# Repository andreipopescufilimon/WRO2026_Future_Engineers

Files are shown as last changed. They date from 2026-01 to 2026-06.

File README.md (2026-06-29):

# WRO2026 Future Engineers – HyperLine Robotics Team
---

Repository of HyperLine Robotics Team competing in the **World Robot Olympiad (WRO) 2026**, Future Engineers category. 

### 🔗 Links

<p align="left">
  <a href="https://hyperlinerobotics.com/" target="_blank">
    
  </a>

  <a href="https://www.youtube.com/@HyperLineRobotics_Team" target="_blank">
    
  </a>

  <a href="https://www.instagram.com/hyperlinerobotics_team/" target="_blank">
    
  </a>

  <a href="https://x.com/HLR_Team" target="_blank">
    
  </a>

  <a href="https://www.facebook.com/hyperlineroboticsteam" target="_blank">
    
  </a>

  <a href="https://github.com/andreipopescufilimon" target="_blank">
    
  </a>

  <a href="https://oshwlab.com/bicicleta11/works" target="_blank">
    
  </a>
</p>

## ❤️ Sponsors and Partners

<table align="center" cellspacing="12">
<tr>
  <td bgcolor="#ffffff" align="center" width="200">
    
  </td>
  <td bgcolor="#ffffff" align="center" width="200">
    
  </td>
  <td bgcolor="#ffffff" align="center" width="200">
    
  </td>
  <td bgcolor="#ffffff" align="center" width="200">
    
  </td>
</tr>

<tr>
  <td bgcolor="#ffffff" align="center">
    
  </td>
  <td bgcolor="#ffffff" align="center">
    
  </td>
  <td bgcolor="#ffffff" align="center">
    
  </td>
  <td bgcolor="#ffffff" align="center">
    
  </td>
</tr>
</table>

---

## 📚 Table of Contents

- [👥 The Team](#the-team)
- [🎯 Challenge Overview](#challenge-overview)
- [🤖 Our Robot](#our-robot)
- [📊 Performance Metrics](#performance-metrics)
- [⚖️ Engineering Trade-Offs](#engineering-tradeoffs)
- [🔬 Testing & Iterations](#testing-iterations)
    - [📊 Quantitative testing](#quantitative-testing)
- [⚙️ Mobility Management](#mobility-management)
  - [🚗 Drivebase](#drivebase)
    - [🔧 Drivetrain](#drivetrain)
    - [⚙️ Torque and Speed Reasoning](#torque)
    - [⚙️ Motor](#motor)
    - [🛞 Wheels](#wheels)
    - [🔌 Motor Driver IFX9201SG](#motor-driver)
    - [🌪️ Impeller](#impeller)
  - [🔄 Steering](#steering)
    - [🔄 Steering Servo Motor](#servo-motor)
  - [📡 Sensor Placement](#sensor-placement)
  - [🏎️ Chassis & Component Mounting](#chassis)
    - [✨ Key Features & Advantages](#key-features)
    - [🔧 Assembly Process](#assembly-process)
      - [🔧 Assembly Process Video](#assembly-process-video)
      - [🔧 3D print the parts](#3d-print-the-parts)
      - [🔧 Assemble the robot](#assembly)
- [🛠️ Power and Sense Management](#power-and-sense-management)
  - [🔋 Li-Po Battery](#li-po-battery)
  - [🖥️ Arduino Nano ESP32](#arduino-nano-esp32)
  - [🧭 IMU Sensor BMI088](#imu-sensor-bmi088)
  - [📷 OpenMV RT1062 Camera](#openmv-rt1062-camera)
  - [⚙️ Drive Motor](#drive-motor)
  - [⚙️ Motor Driver IFX9201SG](#motor-driver)
  - [🔄 Steering Servo MG90S](#steering-servo)
  - [⚙️ Impeller](#impeller)
  - [📏 Pololu PWM Distance Sensor](#distance-sensors)
  - [🔌 Voltage Regulator D24V50F5](#voltage-regulator)
  - [🛠️ PCB Design](#pcb-design)
  - [⚡ Power Consumption](#power-consumption)
  - [🔋 Power and Sensor Validation](#power-and-sensor-validation)
  - [⚠️ Power failure points and mitigation](#power-failure-points)
- [💻 Components coding](#components-coding)
  - [🧠 Software Architecture](#software-architecture)
  - [🔄 Robot State Machine](#state-machine)
  - [⚡ Drive motor](#drive-motor-coding)
  - [🌪️ Impeller](#impeller-coding)
  - [🎮 Servo motor](#servo-motor-coding)
  - [🧭 IMU](#imu-coding)
  - [📡 Distance sensors](#distance-sensors-coding)
  - [📷 Camera](#camera-coding)
- [📝 Obstacle Management](#obstacle-management)
  - [🏁 Open Round](#open-round) 
  - [⚡ Final Round](#final-round)
  - [🅿️ Start from Parking](#start-from-parking)
  - [🅿️ Parking](#parking)
- [⚠️ Edge Cases and Failure Handling](#edge-cases)
- [📽️ Performance Video](#performance-video)
- [💰 Cost Analysis](#cost-analysis)
  - [📦 Component Costs](#components-costs)
  - [🔌 PCB Manufacturing Cost](#pcb-cost)
  - [🖨️ 3D Printing Cost](#3d-printing-cost)
  - [🔩 Other Materials (Screws, Nuts, Miscellaneous)](#other-materials-cost)
  - [💵 Total Cost](#total-cost)
- [🔁 Reproducibility Guide](#reproductibility-guide)
- [🎲 Randomizer](#randomizer)
- [📂 Resources](#resources)
- [📜 License](#license)

## 📂 Folder Structure

This repository is organized as follows:

```
📦 WRO2026_Future_Engineers
├── 📁 3D-models             # Contains 3D design files for the robot's components
│   ├── 📁 old-3D-models     # Previous versions of 3D models
├── 📁 electrical-schematics # Circuit diagrams and wiring
├── 📁 github-commits        # Commit logs and change tracking details for this repository
├── 📁 media                 # Images and videos 
│   ├── 📁 robot-photos      # Photos of the robot
│   ├── 📁 team-photos       # Pictures of team members and teamwork
│   └── 📁 video             # Recorded testing
├── 📁 other                 # Contains files that do not fit into other categories
├── 📁 src                   # Main source code for the robot
├── 📁 technical-draws       # Technical drawings and mechanical blueprints
├── 📁 video                 # Videos of our robot
├── 📄 LICENSE               # MIT License for the project
└── 📄 README.md             # Main documentation for the project
```

---

## 👥 The Team 

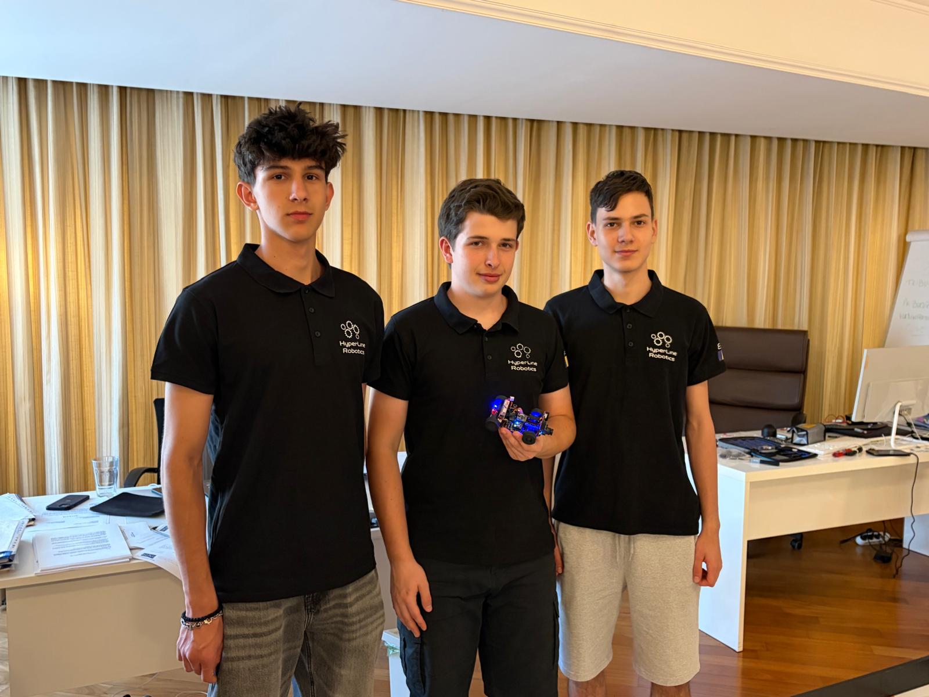
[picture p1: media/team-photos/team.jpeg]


### **Popescu Filimon Andrei Cosmin** (middle)
**Age:** 18 <br>
**High School:** International Computer High School Bucharest (ICHB)  
**View my portofolio**: [https://andreipopescufilimon.com/](https://andreipopescufilimon.com/)

**Description:**  
Hi! I’m Andrei from Romania, and this is my sixth WRO season. This is my second season in Future Engineers, as before I competed in the Robomission category. I am passionate about robotics, especially electronics and the latest algorithms and tech. Over the years, I have worked on multiple robotics projects, including line followers, sumo bots, and air quality modules. I am the founder of HyperLine Robotics Team, where I build and develop advanced robotics projects with my team. Apart from robotics, I also enjoy cybersecurity, programming, and cycling.

---

### **Horia Simion** (left)
**Age:** 17 <br>
**High School:** National College "Mihai Viteazul" (CNMV)

**Description:**  
Hi! I’m Horia from Romania, and this is my third WRO season competing alongside Andrei. I have participated in RoboMission multiple times, gaining valuable experience in solving various problems that may arise while building a robot. I have a strong interest in technology and robotics and am always eager to learn and experiment with new ideas!

---

### **Eduard Alexandru Vasile** (right)
**Age:** 16 <br>
**High School:** Liceul Teoretic Alexandru Ioan Cuza

**Description:**  
Hi! I’m Eduard from Romania. I’m passionate about robotics, especially building and testing competitive robots. I have worked on sumo robots, and recently I started developing line follower robots as well. I also enjoy driving and flight simulators, where I like exploring realistic control, precision, and performance.

Apart from robotics, I love MTB, video games, and cybersecurity. I’m always interested in learning new technologies, improving my skills, and working on projects that challenge me both technically and creatively.

---

## 🎯 Challenge Overview 

The **WRO 2026 Future Engineers** challenge pushes teams to develop a **fully autonomous vehicle** capable of navigating a **dynamic and randomized racetrack** using **sensors, computer vision, and advanced control algorithms**. The goal is to complete **multiple laps** while adapting to randomized obstacles, following **strict driving rules**, and successfully executing a **parallel parking maneuver** at the end of the course.

### 📌 Competition Format 

- **🏁 Open Challenge**: The vehicle must complete **three (3) laps** on a track with **randomly placed inside walls**.

- **🚦 Obstacle Challenge**: The vehicle must complete **three (3) laps** while detecting and responding to **randomly placed red and green traffic signs**:
  - 🟥 **Red markers** ➜ The vehicle must stay on the **right side of the lane**.
  - 🟩 **Green markers** ➜ The vehicle must stay on the **left side of the lane**.
  
  After completing the three laps, the vehicle must **locate the designated parking zone** and perform a **precise parallel parking maneuver** within a limited space, adding an extra layer of difficulty.
  
- **📑 Documentation**: Each team must maintain a **public GitHub repository** showcasing their **engineering process, vehicle design, and source code**.

### 🏆 Scoring & Evaluation
Scoring is based on **accuracy, technical documentation and speed**, rewarding teams that balance **efficiency, adaptability, and innovation**. This challenge not only tests **robotics and programming skills** but also promotes **problem-solving, teamwork, and engineering creativity**.

🔗 **Find out more about the challenge [here](https://wro-association.org/wp-content/uploads/WRO-2026-Future-Engineers-Self-Driving-Cars-General-Rules.pdf).** 🚀

---

## 🤖 Our Robot 
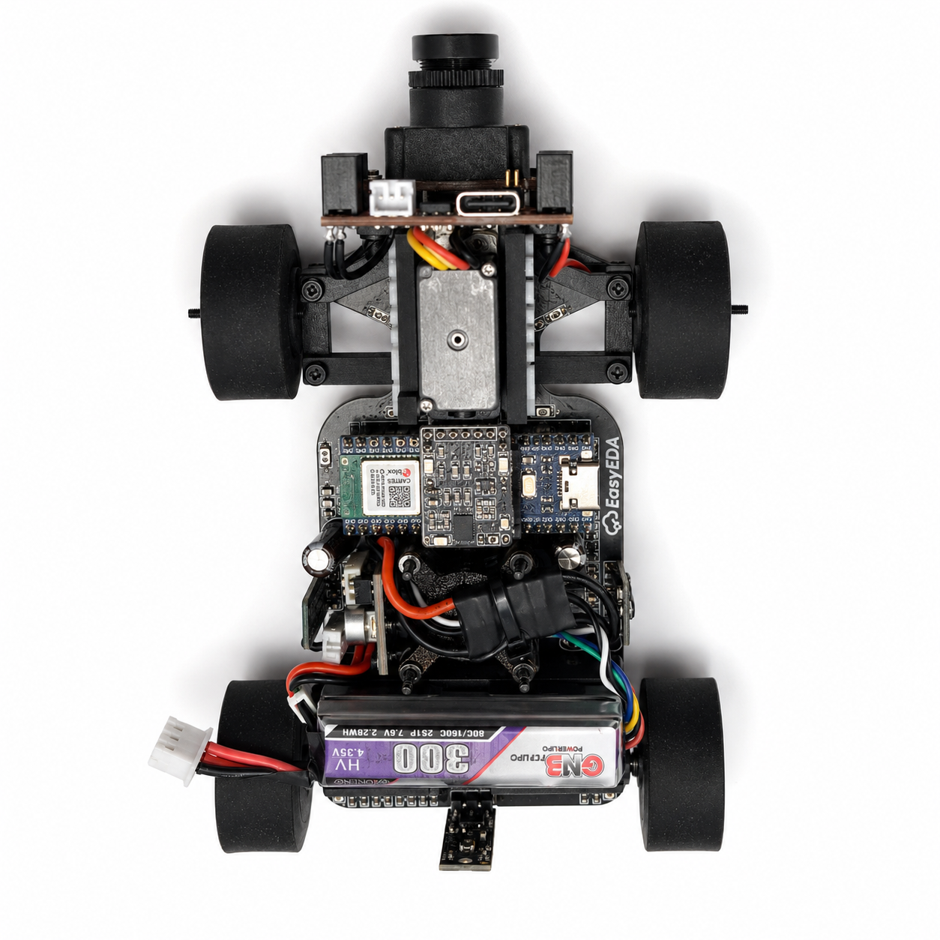
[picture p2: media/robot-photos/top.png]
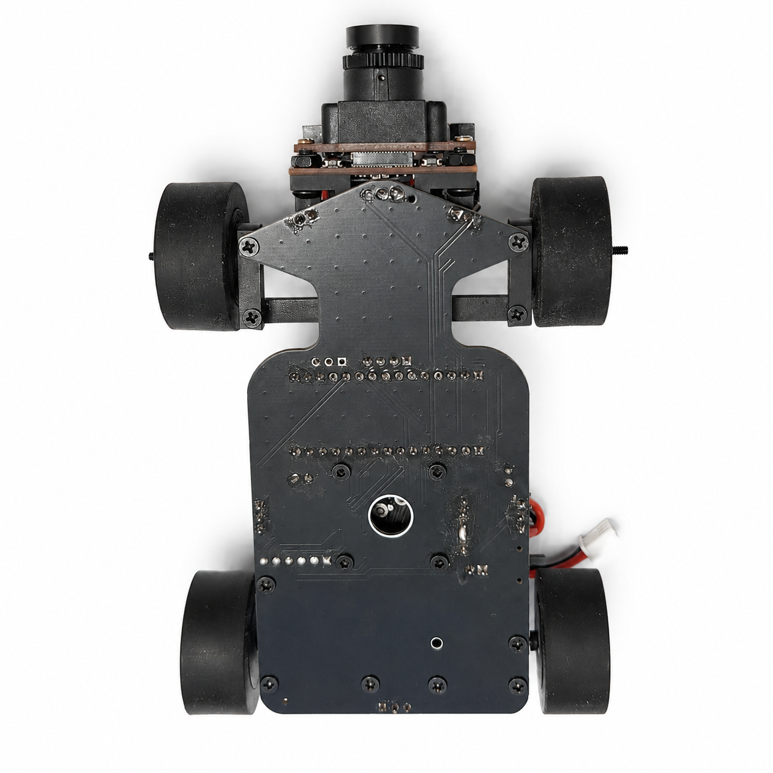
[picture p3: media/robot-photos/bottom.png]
|  |  |
|---|---|
| <p align="center"><b>Top</b></p> | <p align="center"><b>Bottom</b></p> |

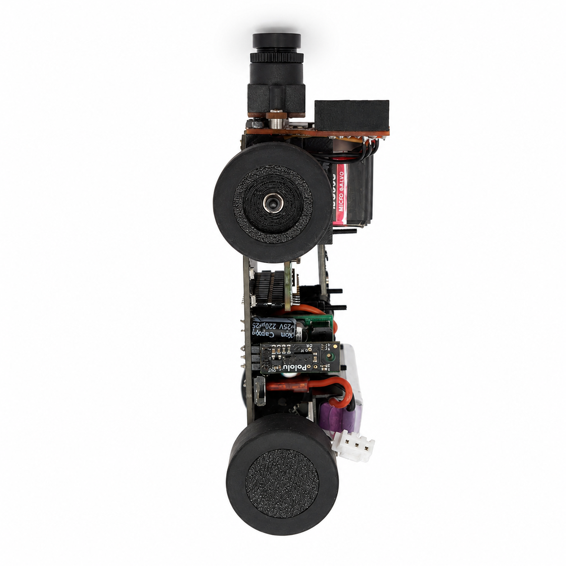
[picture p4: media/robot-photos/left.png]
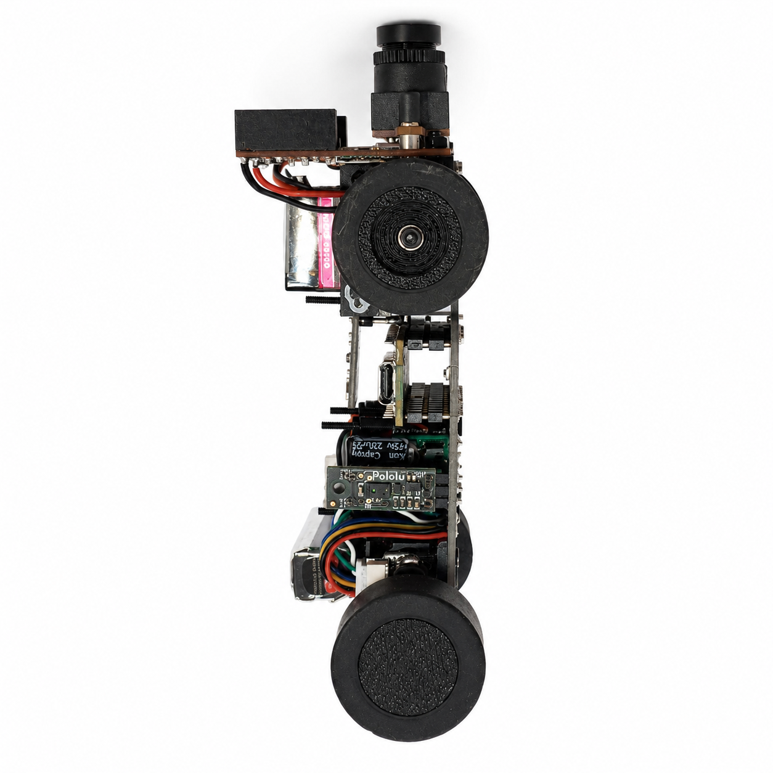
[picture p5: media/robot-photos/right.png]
|  |  |
|---|---|
| <p align="center"><b>Left</b></p> | <p align="center"><b>Right</b></p> |

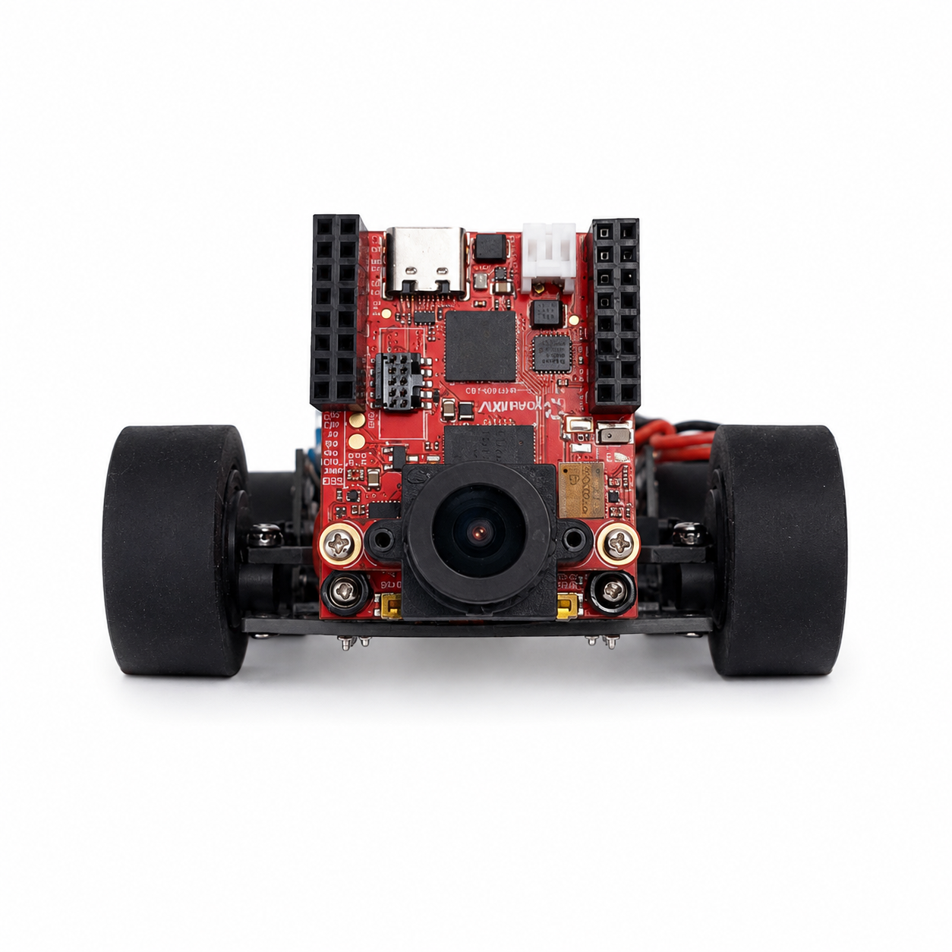
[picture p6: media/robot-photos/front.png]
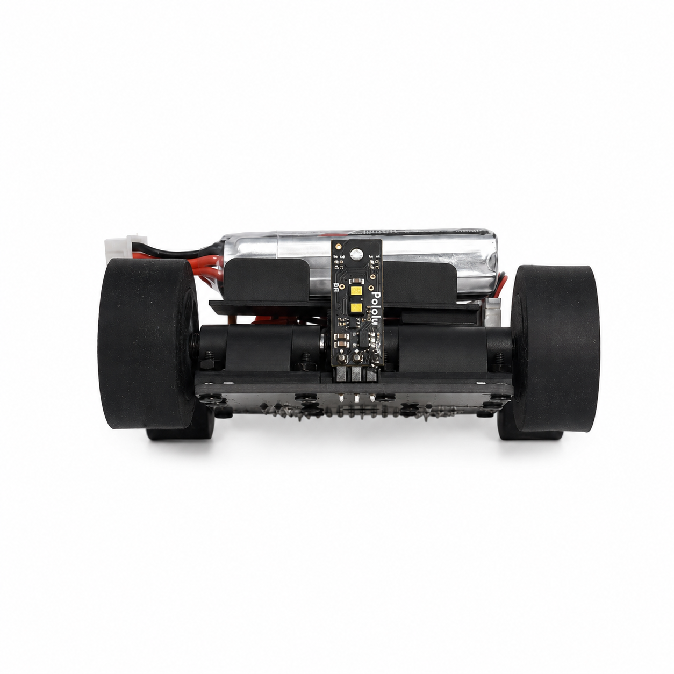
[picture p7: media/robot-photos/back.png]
|  |  |
|---|---|
| <p align="center"><b>Front</b></p> | <p align="center"><b>Back</b></p> |

Robot Specifications:
| Parameter | Value |
|---|---|
| Robot Length | ~145 mm |
| Robot Width | ~65 mm |
| Robot Height | ~55 mm |
| Total Weight | ~200 g |
| Wheelbase | ~65 mm |
| Ground Clearance | ~6 mm |
| Main Controller | Arduino Nano ESP32 |
| Vision System | OpenMV RT1062 |
| Drive System | Rear differential drive |
| Steering System | Parallel steering |
| Drive Motor | Pololu 30:1 HPCB Gearmotor |
| Steering Servo | MG90S |
| Downforce System | 10000KV BLDC Impeller |
| Battery | 2S Li-Po 300mAh |
| Maximum Stable Speed | ~3 m/s |
| Camera Processing Speed | ~40 FPS |
| Maximum Steering Angle | ~85° |
| Peak Current Consumption | ~7 A |
| Communication Protocols | UART, I2C, PWM |
| Chassis Type | Custom PCB chassis |
| Wheel Material | Cast silicone tires |

The robot was designed to prioritize stability, fast steering response, and compact packaging. A lightweight PCB chassis combined with silicone tires and an active downforce system allows the robot to maintain traction and consistency during high-speed autonomous runs.

---

## 📊 Performance Metrics 

The robot was tested extensively on full-scale WRO-inspired tracks to evaluate stability, obstacle handling, and parking consistency. Multiple runs were performed under different lighting conditions and track layouts to validate reliability and repeatability.

| Metric | Result |
|---|---:|
| Maximum stable speed | 3 m/s |
| Average lap time | 11-12 s |
| Parking success rate | 90% |
| Obstacle avoidance success rate | 95% |
| Average steering correction delay | <10 ms |
| Camera processing speed | ~40 FPS |
| Maximum steering angle | 85° |
| Full system peak current | ~7 A |

The final tuning focused on balancing speed and stability rather than maximizing raw speed alone. Particular attention was given to repeatable obstacle avoidance and consistent parking performance.

---

## ⚖️ Engineering Trade-Offs 

Throughout the development process, every major design choice had to balance speed, stability, reliability, weight, and ease of debugging. The goal was not only to build a fast robot, but to create a compact autonomous vehicle that can perform consistently across different WRO field layouts, lighting conditions, obstacle positions, and parking scenarios.

| Decision | Chosen Solution | Reason |
|---|---|---|
| Main controller | Arduino Nano ESP32 | Compact board with enough processing power for real-time control, integrated wireless features for debugging, and good compatibility with our sensors and actuators |
| Vision system | OpenMV RT1062 | Lower latency, lower power consumption, and easier real-time color processing compared to a Raspberry Pi-based system |
| Chassis structure | PCB chassis | Reduces wiring, improves rigidity, saves space, and makes the robot easier to assemble and reproduce |
| Steering system | Parallel steering | Simpler, lighter, and more compact than Ackermann steering, while still giving predictable steering response |
| Navigation | Gyro-based PD control | More stable heading correction than relying only on encoder movement, especially during long straights and after obstacle avoidance |
| Tires | Cast silicone tires | Provide high grip and predictable handling on smooth WRO surfaces |
| Downforce system | Impeller | Increases traction during acceleration, braking, and cornering without adding static weight |
| Obstacle detection | Camera-based detection | Allows flexible detection of randomized red and green traffic signs, track lines, and parking elements |

The final robot design focuses on reliable autonomous behavior in a compact and lightweight structure. Instead of optimizing only one area, such as maximum speed, we designed the mechanical, electrical, and software systems to support each other. The chassis keeps the robot rigid, the tires and impeller improve grip, the camera provides high-level field information, and the gyro helps maintain stable heading control.

### Main Engineering Constraints

During development, several constraints directly influenced the final design. These constraints helped us decide which solutions were practical, reliable, and suitable for competition use.

| Constraint | Design Challenge | Final Solution |
|---|---|---|
| Limited robot size | The robot had to remain small enough for tight turns, obstacle avoidance, and parking | Short wheelbase, compact drivetrain, PCB chassis, and low component stacking |
| Low weight target | Extra weight reduces acceleration, braking performance, and steering response | Lightweight PCB chassis, compact electronics, and 3D-printed structural parts |
| High current peaks | The impeller, drive motor, and steering servo can create sudden voltage drops | 2S Li-Po battery, dedicated voltage regulation, short power traces, and clean PCB routing |
| Camera latency | Delayed detection can cause late turns or incorrect obstacle avoidance | OpenMV RT1062 used for fast image processing and direct UART communication with the controller |
| Steering precision | Small steering errors can accumulate over multiple laps and affect parking accuracy | Servo-based steering combined with gyro correction and camera-based decisions |
| Mechanical stability | Vibration and chassis flex can affect camera view, sensor readings, and steering accuracy | Rigid PCB chassis, fixed component mounting, and compact mechanical structure |

These constraints shaped the robot as a complete system. The mechanical design provides grip, rigidity, and compact packaging. The power system keeps the electronics stable during current peaks. The sensors give the software reliable information about the track, obstacles, and robot heading. The software then combines this data to make safe and repeatable autonomous decisions. Because of this, the final design is not just a collection of selected components, but a system where each subsystem was chosen to support the others and improve consistency during full autonomous runs.

---

## 🔬 Testing & Iterations 

During development, multiple robot revisions were designed and tested to improve steering precision, reliability, and overall track performance. The robot was developed through several iterations. Each version was tested on the main tasks required by the WRO Future Engineers challenge: stable driving, obstacle handling, cornering, and parking.

| Version | Main problem found | Change made | Result |
|---|---|---|---|
| V1 | The chassis was too large and the steering response was slow | Reduced the chassis size and changed the mechanical layout | Better turning response |
| V2 | The robot was reliable on straight sections but less stable during parking | Moved the side sensors closer to the PCB and improved rear distance sensing | More stable parking approach |
| V3 | Obstacle handling needed smoother recovery after passing traffic signs | Added clearer software states for cube following, avoidance, and recovery | More consistent obstacle challenge behavior |

### 📊 Quantitative testing 

| Test | Runs | Success rate | Main failure observed | Improvement made |
|---|---:|---:|---|---|
| Open Challenge full lap driving | 20 | 18/20 | Small steering oscillation near corners | Tuned gyro correction and steering gain |
| Three-lap Open Challenge | 10 | 8/10 | Occasional wide corner exit | Reduced speed during corner entry |
| Red traffic sign passing | 20 | 18/20 | Late detection in low light | Adjusted OpenMV threshold and ROI |
| Green traffic sign passing | 20 | 18/20 | Camera noise on reflective surface | Added color filtering and distance confirmation |
| Obstacle recovery after passing sign | 20 | 17/20 | Robot returned too sharply to the lane | Added smoother recovery state |
| Parking approach | 20 | 16/20 | Rear alignment sometimes too close to boundary | Adjusted rear sensor stopping distance |
| Full Obstacle Challenge with parking | 10 | 8/10 | Parking was the least consistent part | Added rear distance correction and slower final movement |

These tests showed that the robot was mechanically capable of completing the challenge, but reliability depended strongly on software tuning and sensor placement. The largest improvements came from reducing steering oscillation, improving camera threshold stability and using the rear distance sensor during parking to not hit any of the parking walls.

---

## 🚗 Mobility Management 

The robot's mobility is controlled through **a fully PCB chassis, a servo-based steering system, and a drivetrain featuring a custom differential and axes**. These components work together to ensure smooth, **precise movement with optimized traction, stability, and efficient power management**.

## ⚙️ **Drivebase** 

### 🔧 **Drivetrain** 

The drivetrain uses a custom micro-RC differential at the rear, driven by a **Pololu 30:1 HPCB micro gearmotor** through a **3D printed gear** → **differential input gear**. The motor is held in a 3D-printed support with the battery mounted above, keeping the center of mass centered and low. Rear outputs rotate in bearings seated inside a printed part that contains 4 bearings for the wheel axles, this attachment is mounted using M2 screws to the PCB chassis, minimizing friction and parts count. 
At the front, the wheels are fully 3D-printed and each wheel runs on two bearings (inner + outer) for a rigid, wobble-free hub that steers precisely.

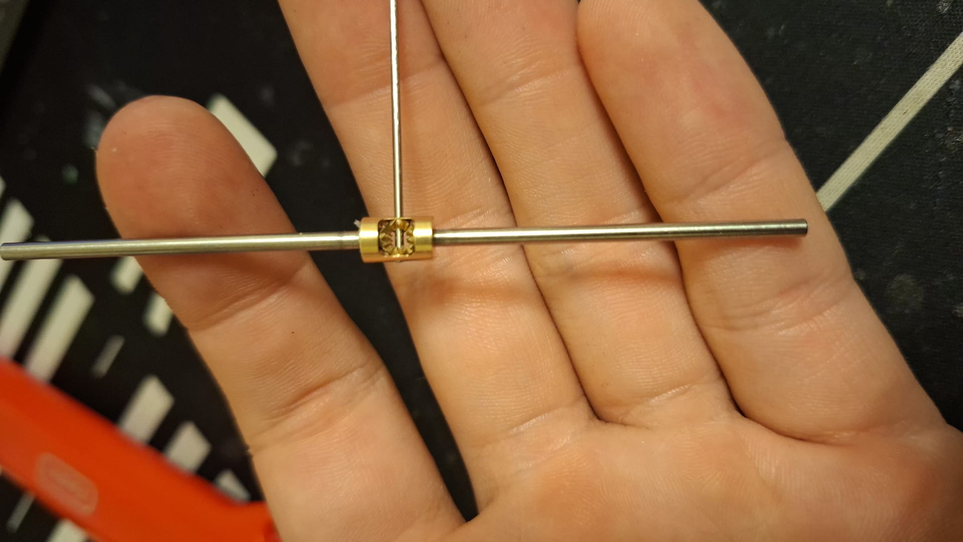
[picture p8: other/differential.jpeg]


To maximize grip on the track without adding mass, we use a **downforce impeller (10000KV BLDC motor)** that pulls air from under the robot, increasing the normal force. The impeller is PWM-controlled via an **EMAX Bullet 20A ESC**. The drive motor is controlled by an **IFX9201SG driver (PWM + DIR)** with an active brake pulse for precise stopping, while the encoder on the gearmotor provides odometry for short, accurate moves (e.g., avoidance hops, parking nudges).

### ⚙️ **Motor – 30:1 Micro Metal Pololu Gearmotor HPCB** 

Following past testing, we selected **a high-power 30:1 Micro Metal Gearmotor (6V)** for the drive system. This motor provides an **optimal balance of speed and torque**, allowing the robot to maintain stability while navigating turns.

|  | **Specifications** |
|---|---|
| **Model:** 30:1 HPCB | **Voltage:** 6V |
| **No-load Speed:** 1000 RPM | **No-load Current:** 120mA |
| **Stall Torque:** ~0.45 kg·cm | **Stall Current:** 1.6A |
| 🔗 **[Buy Here](https://www.pololu.com/product/5184)** | **Function:** Drives the robot |

**Why We Chose This Motor?**  
**- Gear ratio provides sufficient torque** without sacrificing efficiency.  
**- Compact and lightweight design**, allowing integration into a lightweight robot.

### 🛞 Wheels & Tires (Silicone) 

Our robot uses cast silicone tires on 3D-printed hubs. Silicone provides high, repeatable static friction on painted boards and vinyl, which pairs perfectly with the rear differential and downforce impeller—more grip when we need it, without adding mass.

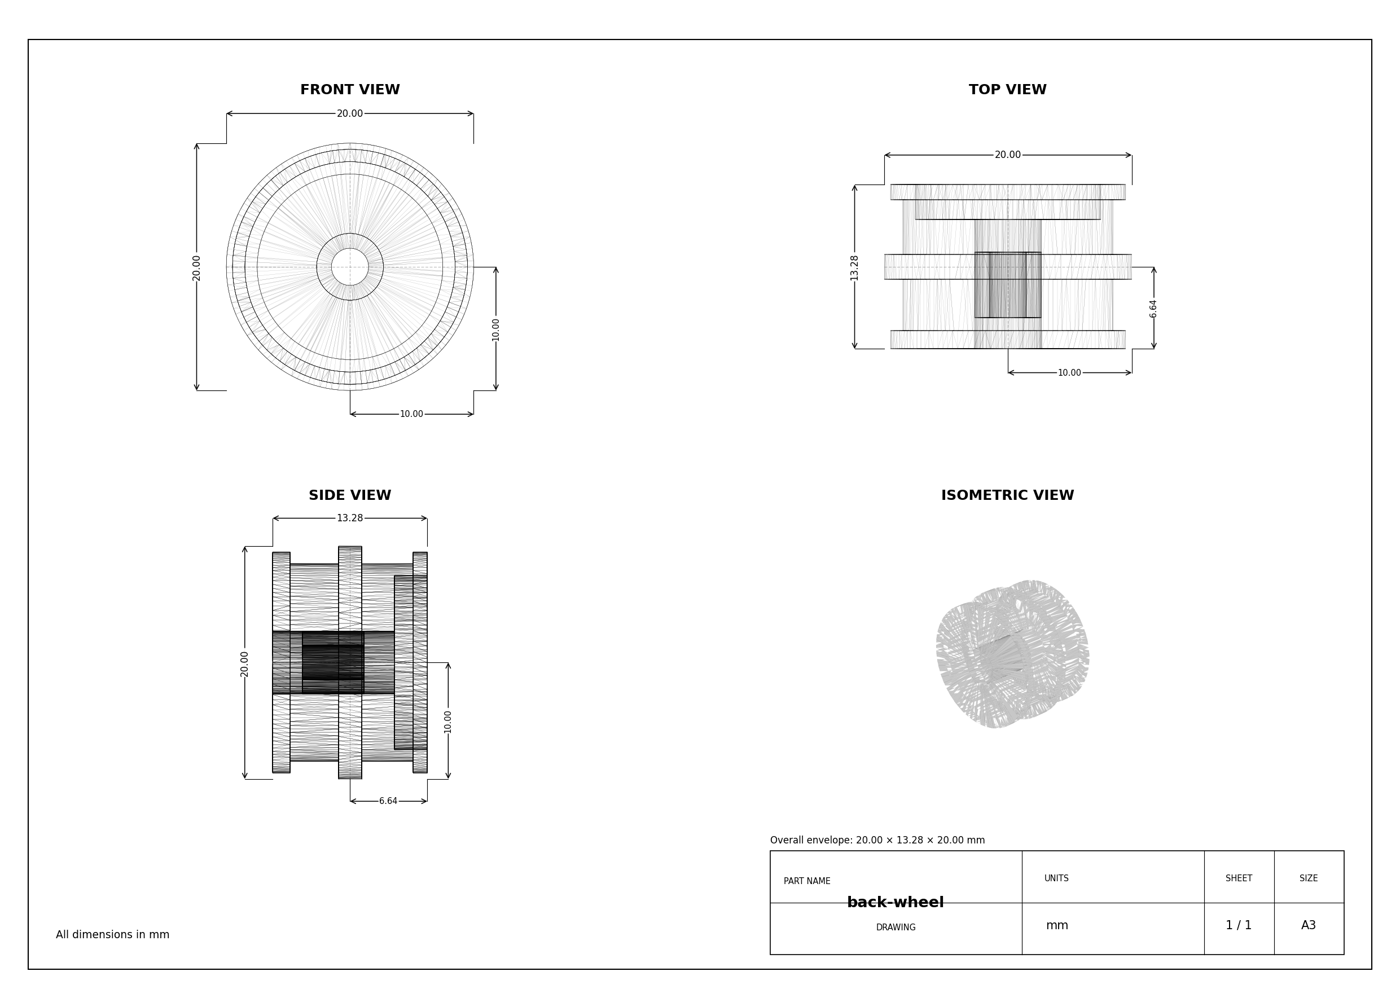
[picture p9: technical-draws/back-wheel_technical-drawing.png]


**Why silicone?**
- Grip & consistency: Strong adhesion on smooth surfaces → faster exits and shorter braking distances.
- Low wear on the map: Softer compound grips without scratching.
- Stable handling: Predictable breakaway, so PD/PID steering stays smooth.

**Construction:**
- Rims: 3D-printed hubs with dual bearings (inner + outer) for a rigid, wobble-free wheel.
- Tire: Cast silicone ring fitted onto a mechanical bead on the rim (no harsh solvents needed).
- Fit: Rear wheels mount directly to the diff axle outputs; fronts ride on steering hubs for low friction.

#### ⚙️ **Torque and Speed Reasoning** 

The 30:1 Pololu HPCB gearmotor was selected because it provides a good balance between speed and usable torque. A lower gear ratio would increase the maximum speed, but the robot would lose acceleration and braking control. A higher gear ratio would give more torque, but the robot would become slower on long straight sections.

The goal was not to choose the fastest possible motor, but the fastest motor that could still:
- accelerate smoothly without wheel slip,
- brake before turns and obstacles,
- recover from small steering errors,
- perform short controlled movements during parking,
- keep enough torque when the impeller increases downforce.
- be reliable and not burn

Because the robot uses silicone tires and an active downforce impeller, the wheels can transfer more force to the ground. This means the drivetrain needs enough torque to use the extra grip without stalling or overheating. The 30:1 gear ratio gave the best compromise during testing, especially for repeated starts, obstacle avoidance movements, and parking corrections.

| Option Considered | Advantage | Disadvantage | Decision |
|---|---|---|---|
| Lower gear ratio motor | Higher theoretical top speed | Less torque, weaker braking, harder parking control | Rejected |
| Higher gear ratio motor | More torque and easier low-speed control | Lower speed on long straights | Rejected |
| 30:1 HPCB gearmotor | Good speed, enough torque, compact size | Needs careful speed control | Selected |

This choice improved the robot’s consistency because the car could drive fast while still keeping predictable control during turns and obstacle sections.

### 🔌 **IFX9201SG Motor Driver** 

The **IFX9201SG** motor driver is used to control the robot’s high-performance drive or impeller motor with precision and efficiency. It supports PWM-based speed control and direction control while integrating advanced protection features, making it ideal for demanding robotics applications. The IFX9201SG is directly integrated into our PCB, ensuring compact design and reliable communication with the Arduino Nano ESP32.

|  | **Specifications** |
|---|---|
| **Model:** IFX9201SG | **Operating Voltage:** 5.5V – 45V |
| **Logic Voltage:** 3.3V / 5V compatible | **PWM Frequency:** Up to 20 kHz |
| **Max Continuous Current:** 5A | **Max Peak Current:** 8A per channel |
| **Control Interface:** PWM + Direction pins | **Built-in Protections:** Overtemperature, Overcurrent, Undervoltage, Short-to-GND/Battery |
| 🔗 **[Buy Here](https://www.lcsc.com/product-image/C112633.html)** | **Function:** Controls drive motors |

### **⚙️ Impeller for downforce** <a id="impeller">

The **impeller** generates downforce to improve the robot’s grip on the track at high speeds. Powered by a **BLDC motor**, it delivers extremely high RPM with minimal weight, making it ideal for competitive line follower and robotracer builds. Its low rotor inertia ensures instant acceleration, while the compact size allows for easy integration.

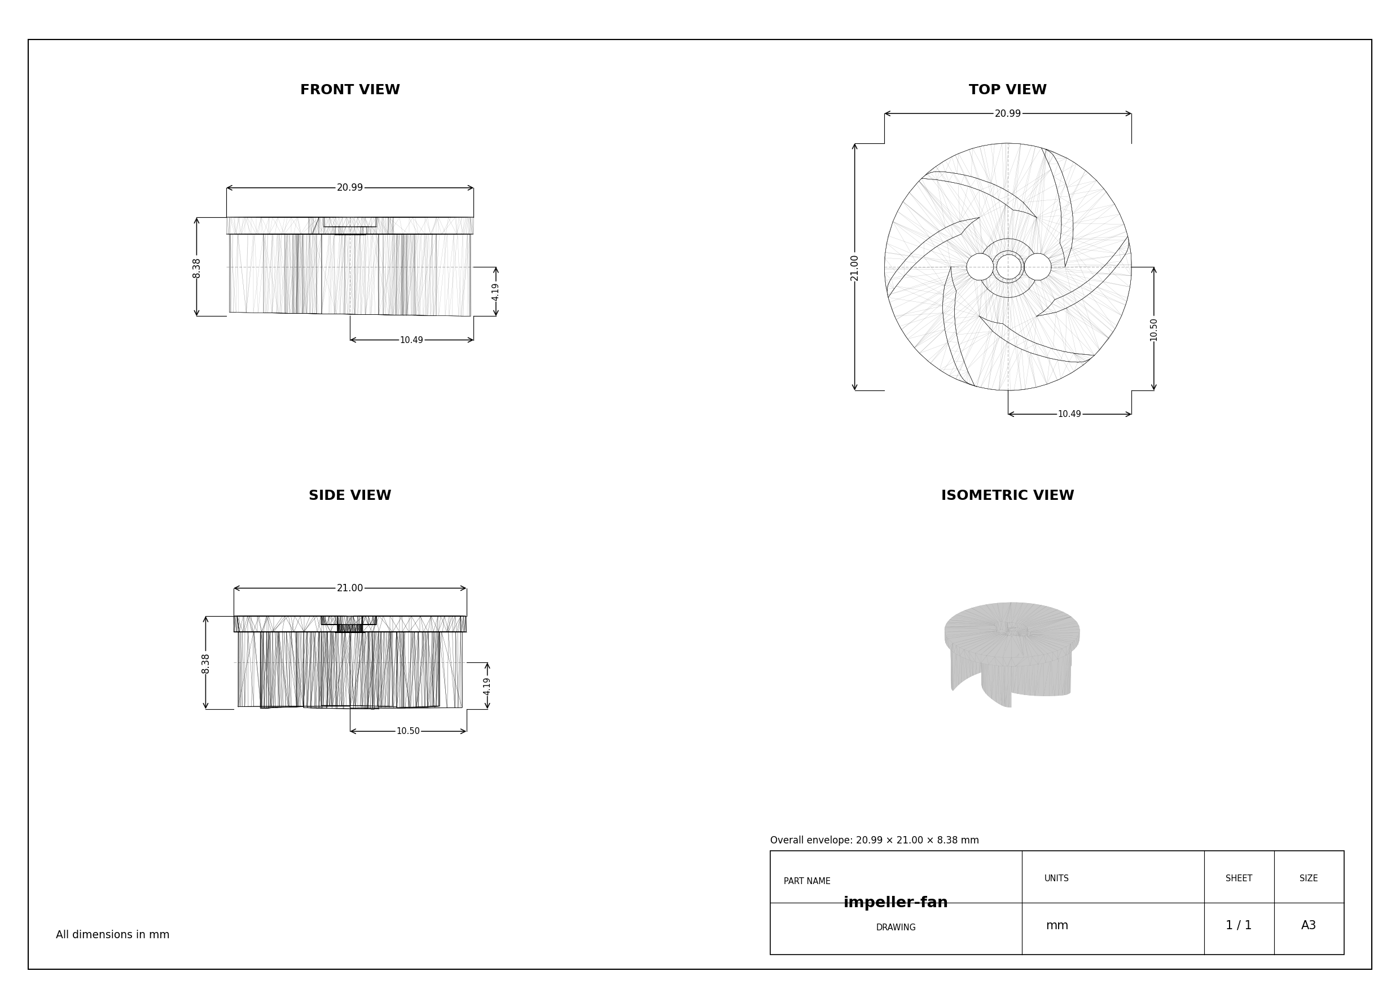
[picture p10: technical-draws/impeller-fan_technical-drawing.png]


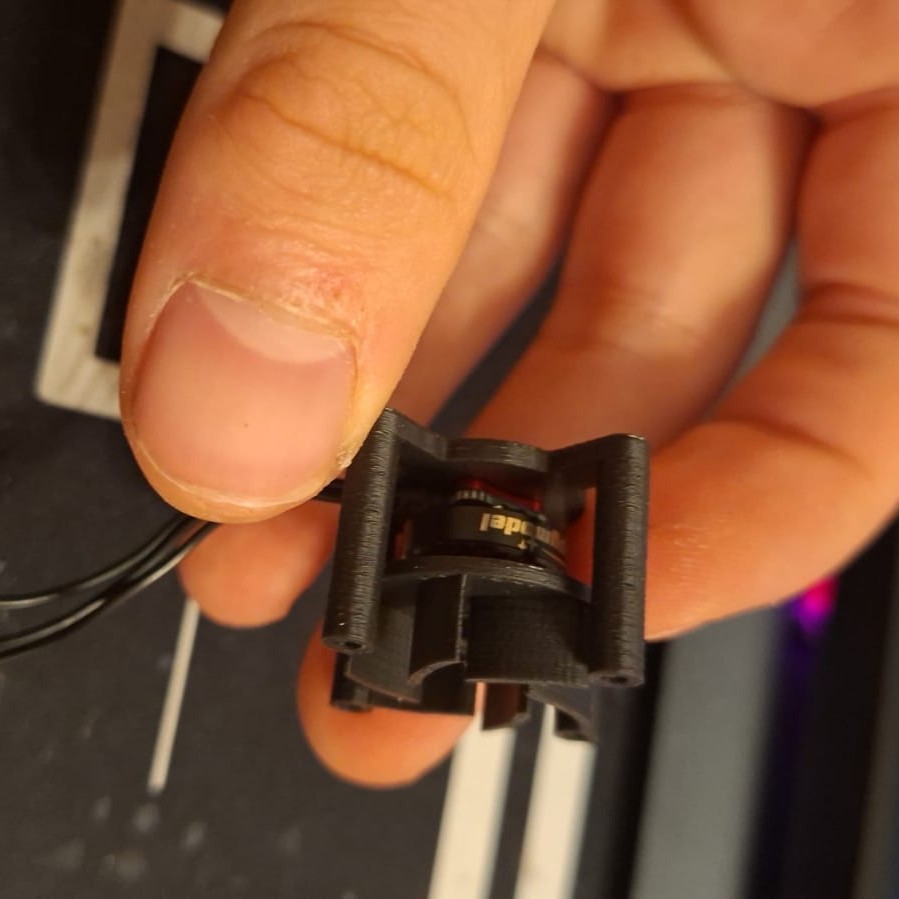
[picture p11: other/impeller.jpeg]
|  | **Specifications** |
|---|---|
| **Type:** BLDC Motor | **Model:** 10000KV |
| **Voltage:** 2–3S | **Shaft Diameter:** 1.0mm |
| **No-Load Speed:** ~85,000 RPM @ 7.4V	 | **	Weight:** ~4.5g |
| **Current Draw (Avg):** ~1A @ 7.4V	 | **Peak Current:** ~2.5A |
| 🔗 **[Buy Here](https://www.aliexpress.com/item/1005010313915123.html)** | **Function:** Drives the downforce impeller |

---

### **⚙️ ESC Controller for impleller** <a id="ESC">

**The EMAX D-SHOT Bullet 20A ESC controls the BLDC motor that drives the impeller. In this project, it uses a simple servo-style PWM signal, making it easy to interface with the main controller while providing smooth and reliable speed control in a compact, lightweight package.**

|  | **Specifications** |
|---|---|
| **Type:** ESC For BLDC Motors | **Model:** EMAX D-SHOT  |
| **Voltage:** 2–4S | **Protections:** Shortcircuit protection & stall protection |
| **Dimensions (LxW):** 11.9x19.6 mm	 | **Weight(W/O Wires):** ~3.5g |
| **Burst Max Current**  : ~30A	 | **Max Current:** ~20A |
| 🔗 **[Buy Here](https://emaxmodel.com/products/emax-d-shot-bullet-series-20a-2-4s-blheli_s-esc-3-5g-support-onshot42-multishot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)** | **Function:** Drives the downforce BLDC |

---

## 🔄 **Steering** 

The **steering system** is a critical part of the robot, ensuring precise maneuverability and smooth turns. Our design is based on a **parallelogram steering mechanism**, where both front wheels turn at the same angle through a single servo-controlled linkage. This setup provides predictable and stable steering, making it easy to use for an autonomous vehicle. Instead of using an **Ackermann steering system**, which requires more complex calculations and linkages, we opted for a **simpler and more lightweight solution** that offers consistent control. Our steering system allows for a maximum turning angle of 80 degrees in both the left and right directions. This range provides precise maneuverability, enabling the robot to navigate sharp turns efficiently while maintaining stability.

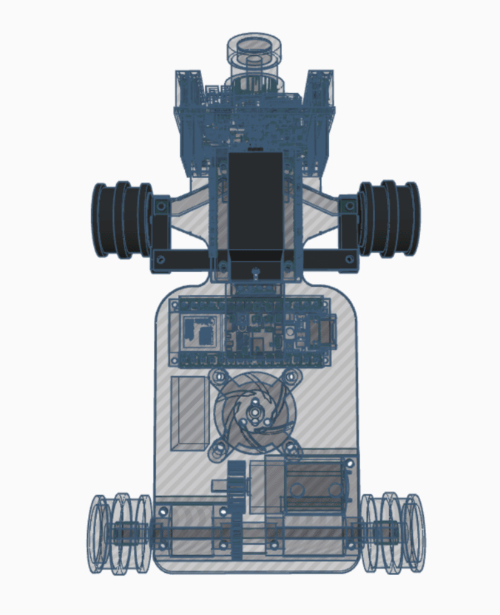
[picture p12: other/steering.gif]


Our **steering arm is directly connected to the servo**, which moves the two front wheels simultaneously. This ensures that the turning response is immediate and proportional to the servo's motion. The **wheels are mounted on special mounts hubs**, allowing for smooth and precise movement without excessive friction. To ensure **structural integrity and long-term reliability**, the steering system is **assembled using M2 screws on which the hubs can turn**. 

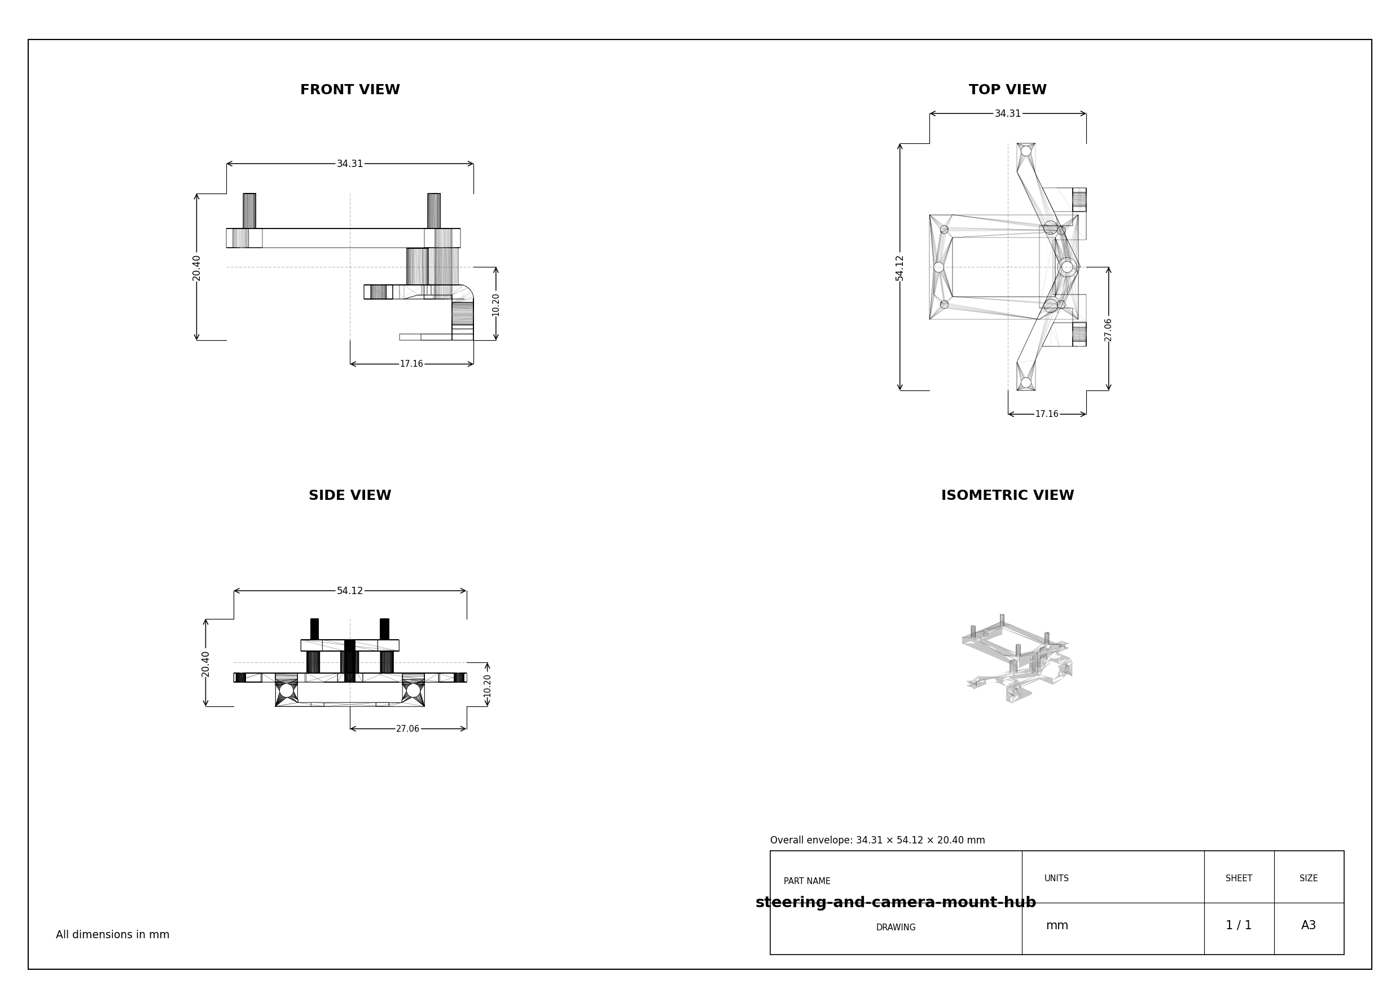
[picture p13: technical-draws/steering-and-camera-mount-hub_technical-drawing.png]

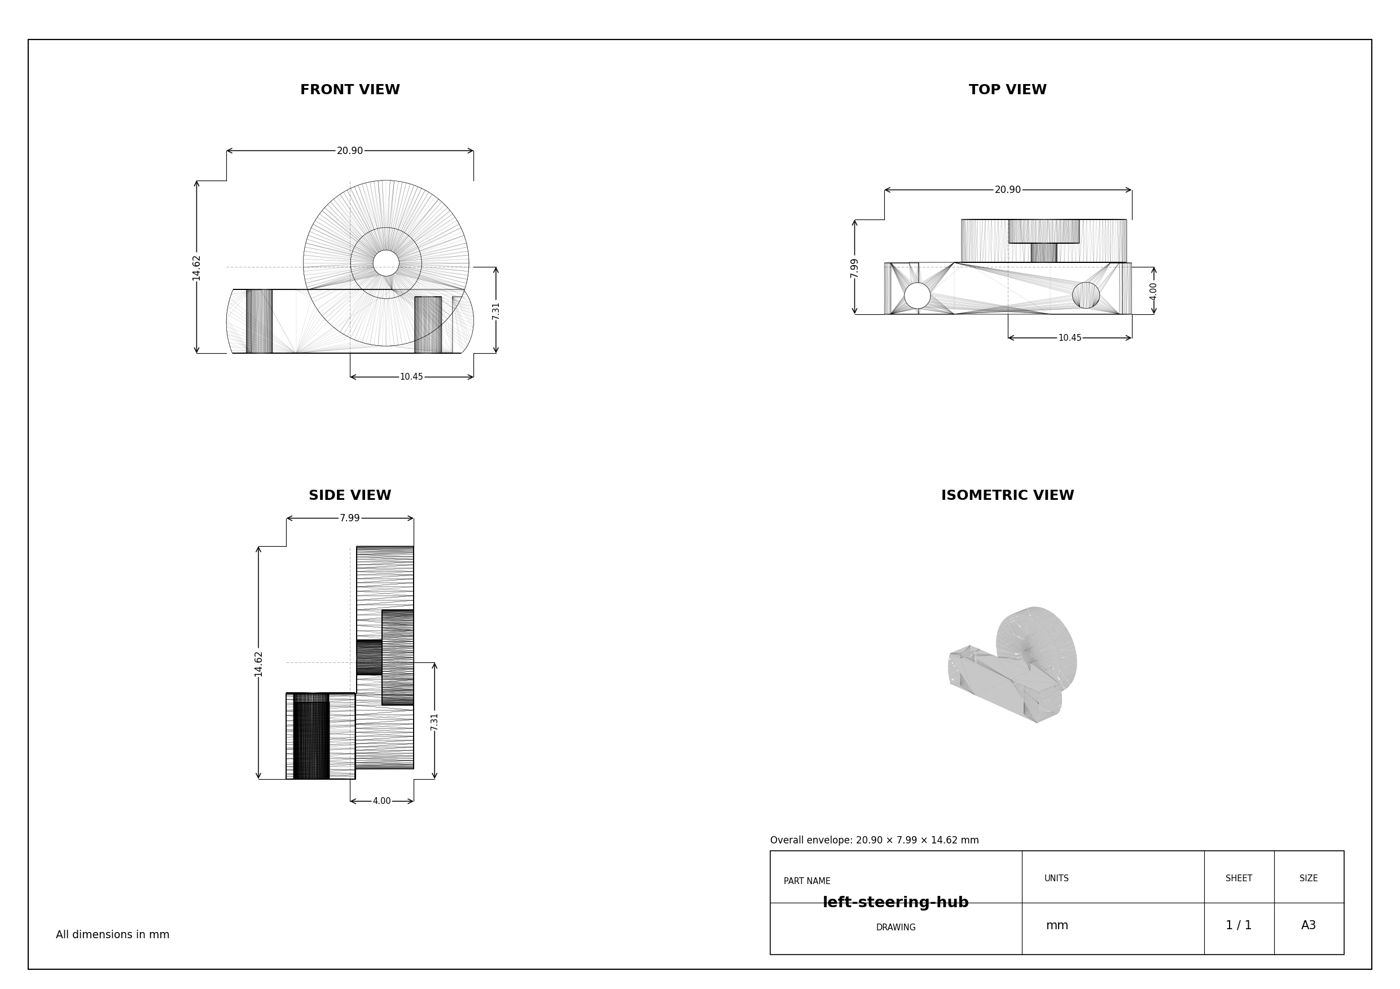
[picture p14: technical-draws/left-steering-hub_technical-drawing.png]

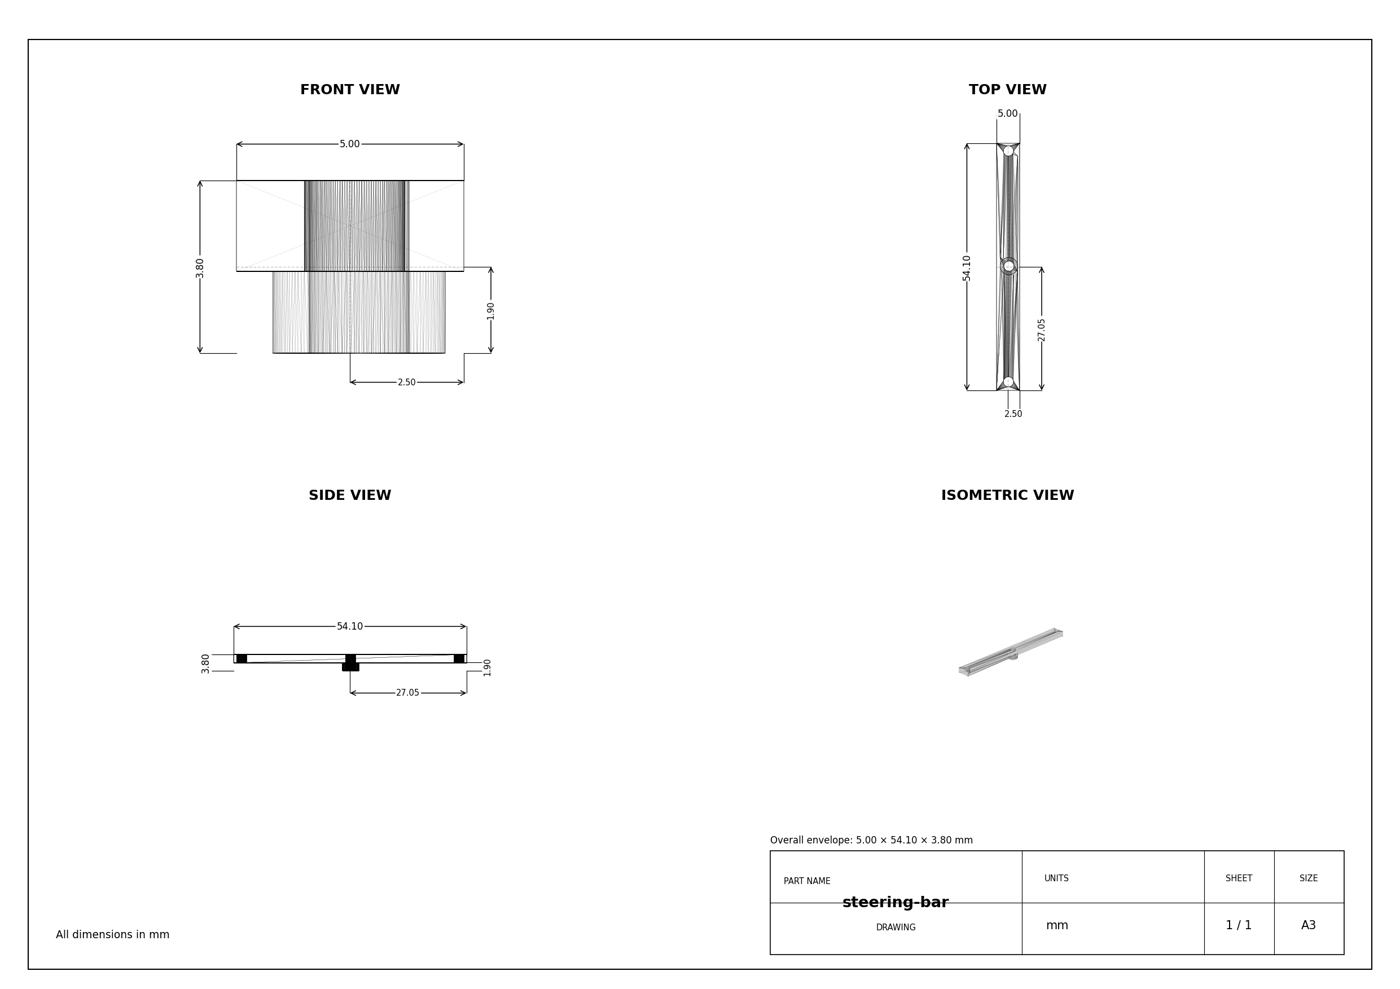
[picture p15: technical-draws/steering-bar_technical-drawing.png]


---

### **🔄 Steering Servo – MG90S** 

To control the steering system, we use an **MG90S micro servo**, known for its high torque and fast response. This servo enables quick and precise adjustments while maintaining a compact and lightweight design. Featuring **metal gears**, it ensures durability and reliability over extended use. The servo is securely mounted onto the chassis with two screws, and the steering arm is directly attached to its output shaft, providing smooth and efficient motion transfer for accurate steering.

|  | **Specifications** |
|---|---|
| **Model:** MG90S | **Voltage:** 5V |
| **Torque:** 2.2kg/cm | **Signal Type:** PWM |
| **Current Draw (Avg):** 120mA | **Peak Current:** 500mA |
| **Weight:** ~13.4g | **Gears:** Plastic |
| 🔗 **[Buy Here](https://www.optimusdigital.ro/ro/motoare-servomotoare/271-servomotor-mg90s.html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)** | **Function:** Controls steering |

---

## 📡 Sensor Placement Reasoning Using Field Geometry 

The front camera is placed at the front of the robot because it must detect traffic signs before the vehicle reaches them. This gives the software enough time to decide whether the robot must pass the object on the left or on the right. The camera is used mainly for color and position detection, while the laser distance sensors are used for distance stability and alignment.

The front laser sensor is placed near the camera because both sensors observe the same forward driving area. The camera gives the color and horizontal position of the obstacle, while the laser gives distance information. This combination reduces false decisions because the robot does not rely only on color detection.

The side laser sensors are placed closer to the PCB and slightly behind the front axle. This position was selected because side distance correction is more stable after the robot begins steering. If the side sensors are placed too far forward, they react too early and can create steering oscillations. If they are placed too far back, the robot reacts too late near corners and parking boundaries. The selected position gives a better balance between early detection and stable correction.

The rear sensor is used mainly during parking. During parallel parking, the robot needs to know when the back of the vehicle is close to the parking limitation. A rear-facing distance sensor gives a direct measurement of this distance and allows the robot to stop before touching the parking lot boundaries.

Each laser sensor has an approximate field of view of 40 degrees. Because of this, the sensors are angled so that their detection cones cover the useful areas around the robot without crossing too much into blind or irrelevant zones. The side sensors cover the lateral wall area, the front sensor covers the forward path, and the rear sensor covers the parking alignment zone.

### Sensor placement trade-offs

| Placement option | Advantage | Problem | Final decision |
|---|---|---|---|
| Front-only sensors | Simple wiring and early detection | Weak parking and side alignment | Not used alone |
| Side sensors very far forward | Detects walls early | Causes oscillation in corners | Rejected |
| Side sensors close to PCB | Stable correction and easier wiring | Slightly later detection | Selected |
| Rear sensor removed | Lower weight and simpler wiring | Parking becomes less reliable | Rejected |
| Camera-only obstacle detection | Detects color and position | Distance estimation is weaker | Combined with laser sensor |

You can see the placement belod:

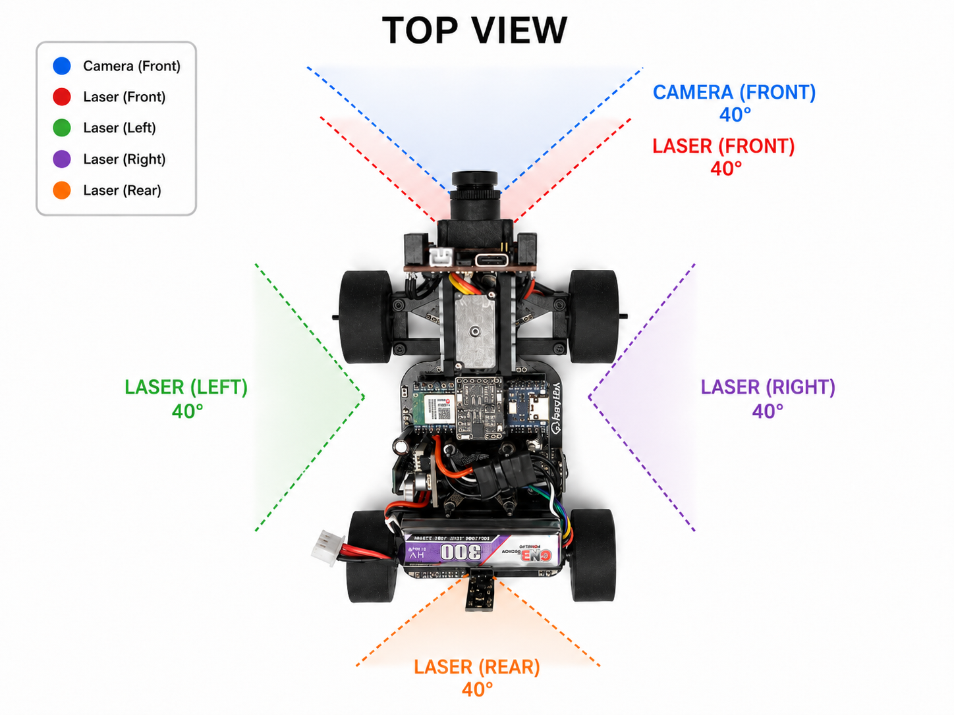
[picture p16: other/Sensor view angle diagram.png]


---

## 🏎️ **Chassis & Component Mounting** 

The chassis of our robot is built around a custom PCB structure, which acts both as the electrical base and as the main mechanical frame. This design helps reduce unnecessary wiring, saves space, improves rigidity, and keeps the robot compact enough for fast movement inside the track.

Instead of using a fully 3D-printed frame, we chose a PCB chassis because it gives better precision for mounting electronic components and keeps the wiring much cleaner. The main controller, motor driver, voltage regulator, connectors, IMU, and sensor connections are all integrated directly into the board. This reduces the risk of loose wires during testing and makes the robot easier to repair or debug.

The mechanical parts are mounted directly onto the PCB using M2 screws, nuts, and small 3D-printed supports. Each printed part was designed to match the exact position of the robot components, so the drivetrain, steering system, battery, impeller, and sensors stay fixed during high-speed runs. The drive motor is mounted in a 3D-printed support at the rear of the robot. It transfers motion to the rear differential through a small gear system. The rear axle assembly is supported with bearings to reduce friction and improve stability. This setup allows the rear wheels to rotate smoothly while keeping the drivetrain compact. The steering system is placed at the front of the robot. The MG90S servo is mounted securely on a 3D printed mount that also holds the camera, and its arm controls both front wheels through a parallelogram steering linkage. The front hubs rotate on M2 screws and bearings, allowing the wheels to steer with low friction and good precision.

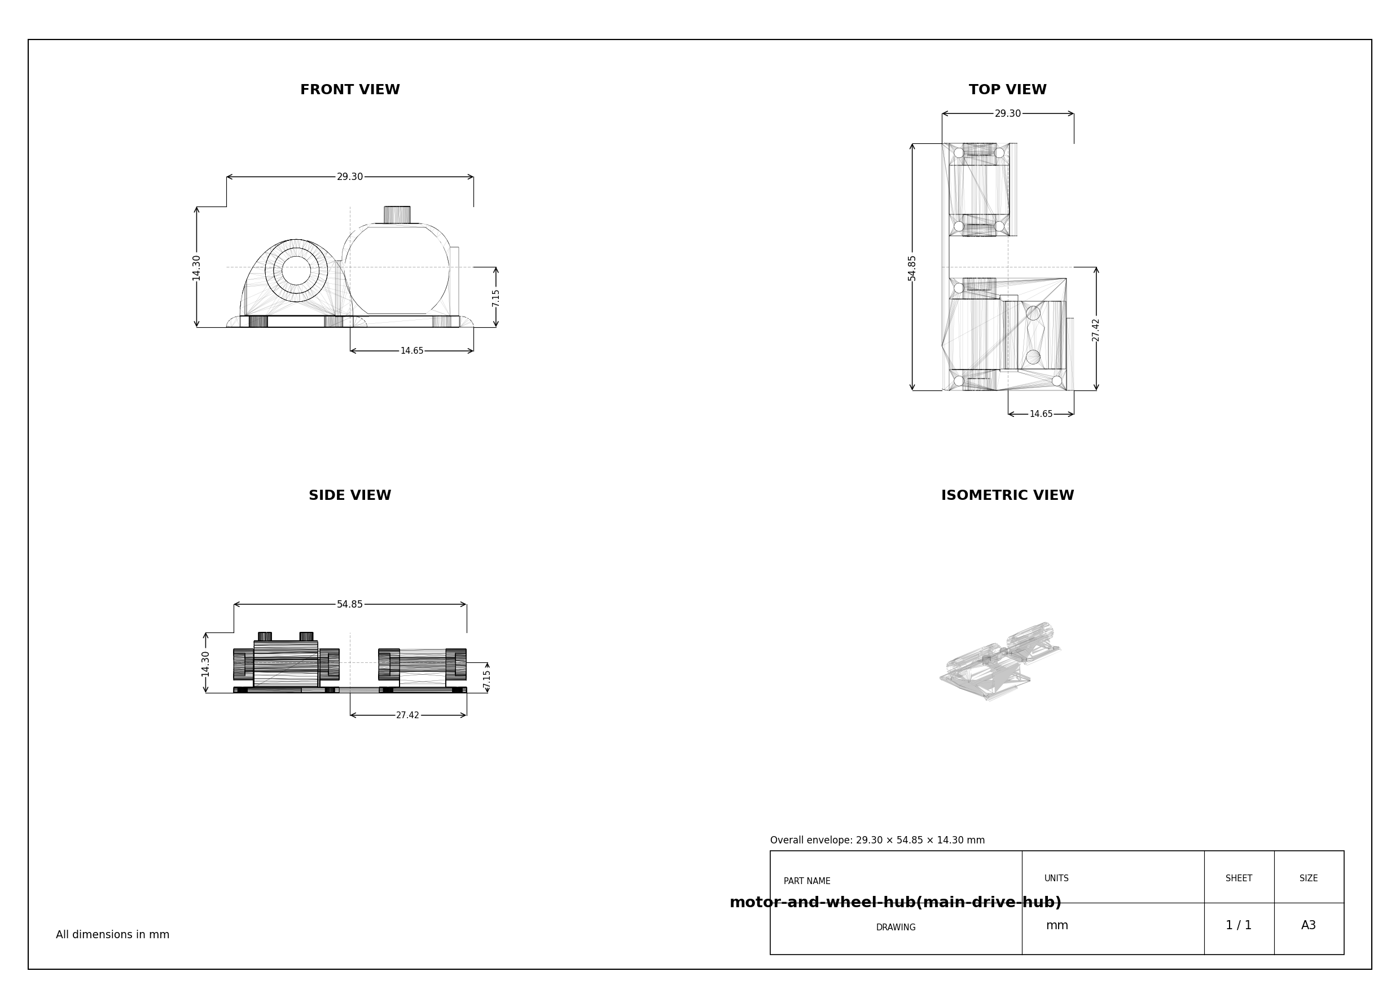
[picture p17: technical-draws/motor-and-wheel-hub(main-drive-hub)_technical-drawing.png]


The battery is mounted close to the center of the robot to keep the center of mass balanced. This helps the robot stay stable when accelerating, braking, or turning. The OpenMV camera is mounted at the front side of the robot via same 3D printed mounting parts used for the steering servo, positioned to clearly detect colored cubes, walls, and track markings. Distance sensors are placed around the robot to assist with wall detection, parking, and starting direction.

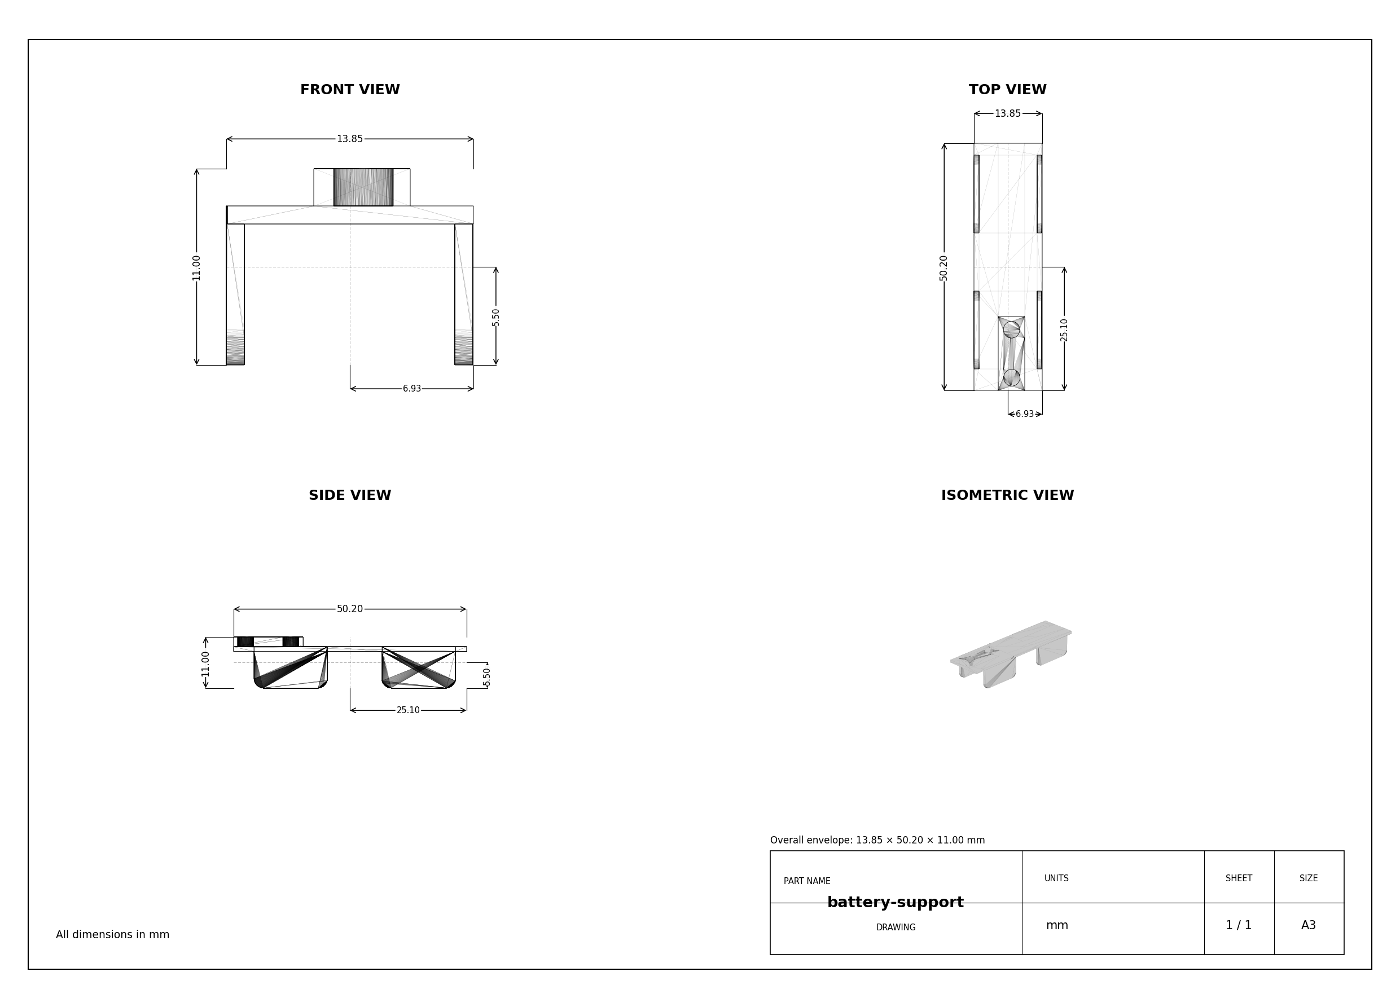
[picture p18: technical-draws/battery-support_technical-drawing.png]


The impeller is mounted in the central area of the chassis so it can pull air from under the robot and generate downforce evenly. This improves grip without adding extra weight, which is important for maintaining speed and control during the run. 

Overall, the chassis and mounting system were designed to be lightweight, rigid, compact, and easy to maintain. Every component has a fixed position, making the robot more reliable during repeated tests and competition runs.

---

## 🔧 Assembly Process 

🔗 **[Click here to watch the assembly video on YouTube](https://youtu.be/HSzWATB6nWQ)** 

The assembly process was planned so that every subsystem could be mounted and tested step by step. This helped us avoid wiring problems, mechanical misalignment, and difficult debugging later in the build.

---

### 2: Assemble the Chassis & Components 

#### 🔧 **Main Assembly Steps**

**1. Prepare the PCB Chassis**

The first step is to inspect the custom PCB chassis and make sure all soldered components, connectors, and mounting holes are clean and correctly placed. Before installing mechanical parts, we check the power rails, continuity, and main connector pins to make sure there are no shorts or soldering problems.

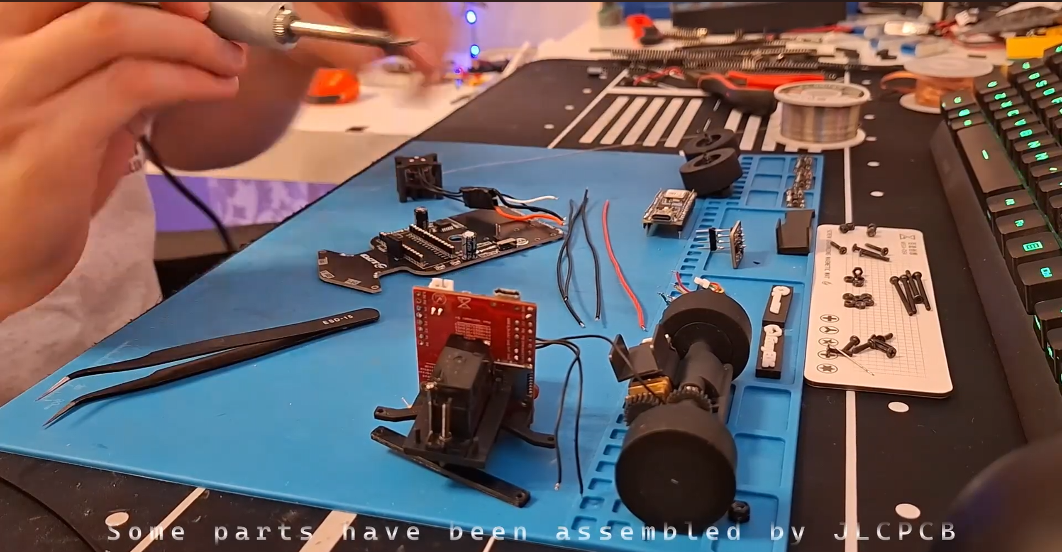
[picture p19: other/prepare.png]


**2. Mount the Rear Drivetrain**

The rear drivetrain is assembled by installing the Pololu 30:1 HPCB gearmotor into its 3D-printed motor support. The motor gear is aligned with the differential input gear, making sure the gears mesh smoothly without too much pressure or backlash.

After that, the rear differential and axle support are mounted to the PCB chassis using M2 screws. Bearings are inserted into the rear support to reduce friction and keep the wheel axles stable during movement.

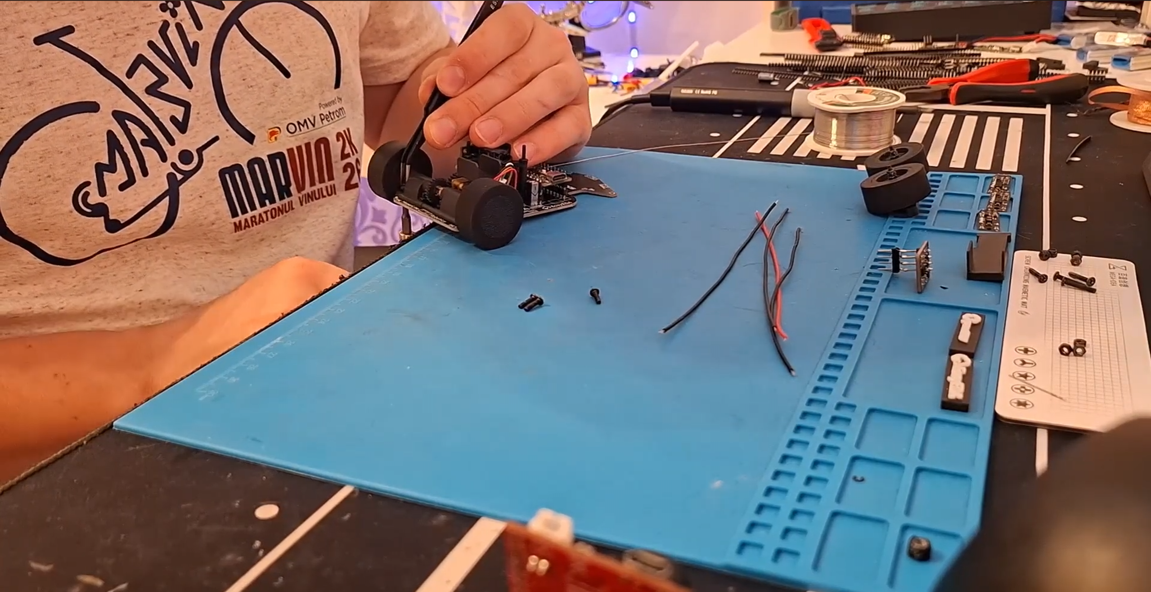
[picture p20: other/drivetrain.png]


**3. Install the Rear Wheels**

The rear wheels are mounted onto the differential outputs. Each wheel is checked to make sure it spins freely and does not wobble. Proper wheel alignment is important because even small friction or imbalance can affect the robot’s stability at high speed.

**4. Assemble the Front Steering System**

The front steering hubs are mounted onto the chassis using M2 screws and bearings. The front wheels are then installed on the hubs and checked for smooth rotation.

The MG90S servo is mounted in its fixed position on the chassis 3D printet part. The steering linkage is connected between the servo arm and both front hubs. Before final tightening, the servo is centered in software, then the wheels are aligned straight. This ensures that the robot drives forward correctly when the servo is at its center position.



**5. Mount the Battery Holder**

The battery support is installed on top of the motor mount, near the middle of the robot to keep the weight balanced. The 2S Li-Po battery is placed securely so it cannot move during acceleration, braking, or sudden turns.

**6. Install the Impeller System**

The impeller base is mounted in the central area of the chassis. The BLDC motor and fan are installed inside the impeller base, making sure the fan spins freely without touching the PCB.
The ESC or MOSFET control wires are connected carefully to the PCB. The impeller is tested at low power first to check vibration, airflow, and stability.

**7. Mount the Camera**

The OpenMV RT1062 camera is mounted at the front side of the robot. Its angle is fixed but already adjusted so it can clearly see the colored cubes, track lines, and wall areas. After mounting, the camera view is tested through the OpenMV IDE to make sure the region of interest matches the physical track.

**8. Install the Distance Sensors**

The Pololu PWM distance sensors are mounted around the robot according to their function: front, back, left, and right. Their position is important for parking, wall detection, and starting direction detection.

Each sensor is mounted via a soldered 3 pin header, so it won't be affected by any vibrations.

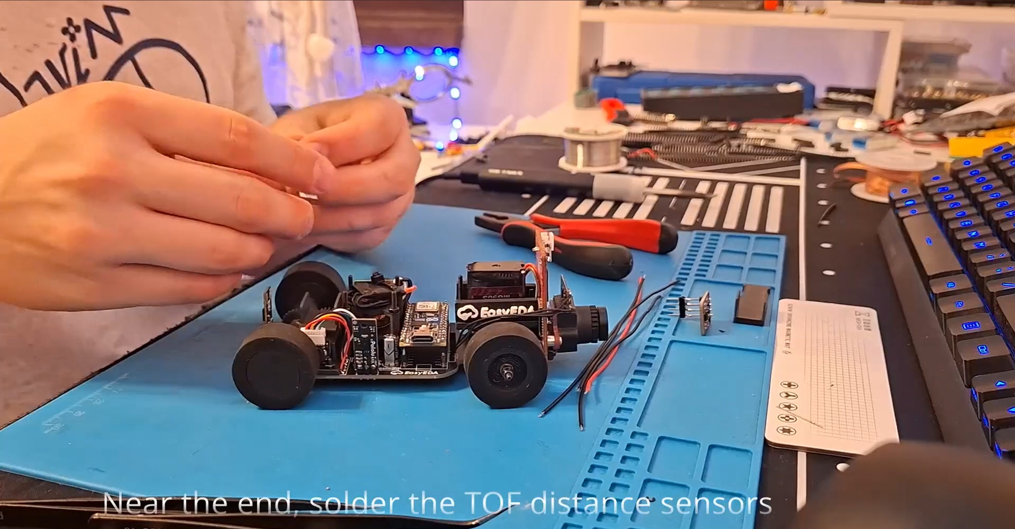
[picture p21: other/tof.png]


**9. Connect Electronics**

After all mechanical parts are mounted, the electronic connections are completed. This includes the motor, encoder, servo, impeller control, OpenMV UART lines, IMU, distance sensors, and battery input. Before powering the full system, we verify polarity and check that the 5V regulator output is stable.

**10. Upload and Test Basic Firmware**

The first firmware test checks each subsystem separately:

- Drive motor forward and reverse
- Steering servo left, right, and center
- Impeller speed control
- Distance sensor readings
- IMU data
- OpenMV UART communication

Testing each part separately makes debugging easier and prevents one faulty subsystem from affecting the whole robot.

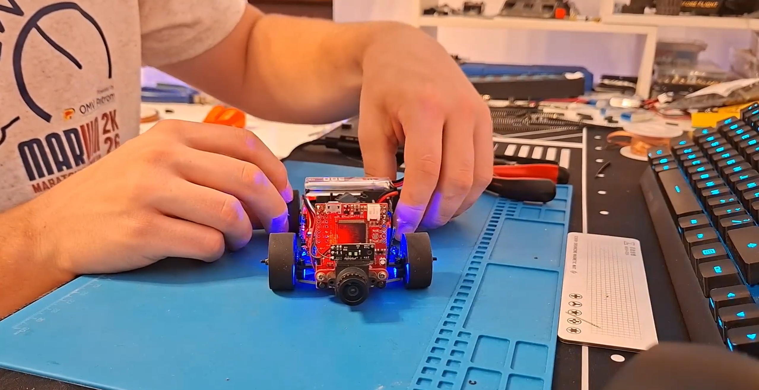
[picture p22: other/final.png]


**11. Final Mechanical Check**

Before running the robot on the track, we check that all screws are tight, the wheels spin freely, the steering moves smoothly, and the battery is fixed properly. We also check that no wires can touch the gears, wheels, or impeller.

**Note:** Small changes are made after each test run until the robot behaves consistently and reliably.

---

## 🛠️ Power and Sense Management 

The robot's **power and sensing system** is designed for **efficiency, precision, and adaptability**. It consists of an **Arduino Nano ESP32, a Li-Po battery, custom BMI088 IMU, OpenMV RT1062 Camera, motors(drive motor and servo motor), and a voltage regulator**, all working together to ensure **stable operation and accurate navigation**.  

Each component has been carefully selected to provide **optimal performance**, minimize power consumption, and ensure **reliability in competition environments**.

---

### **🔋 Li-Po Battery – 2S 300mAh** 

The **Li-Po battery** provides a **compact, lightweight, and high-discharge** power source, making it ideal for our robot. The **7.4V output** is suitable for running our **motors and voltage regulator**, ensuring stable power delivery.

|  | **Specifications** |
|---|---|
| **Model:** 2S Li-Po | **Capacity:** 300mAh |
| **Voltage:** 7.4V | **Discharge Rate:** 60C |
| **Weight:** 12g | **Size:** 13.8 x 12 x 52.5mm |
| **Output Current:** Varies by load | **Connector Type:** JST |
| 🔗 **[Buy Here](https://www.gaoneng.shop/products/gaoneng-gnb-lihv-2s-7.6v-300mah-60c-jst-lipo-battery)** | **Function:** Powers the entire robot |

---

### **🖥️ Arduino Nano ESP32 – Main Controller** <a id="arduino-nano-esp32">

The **Arduino Nano ESP32** provides **high-speed processing, built-in Wi-Fi and Bluetooth, and extensive GPIO capabilities** in a **compact form**. This allows it to handle **sensor data, motor control, and vision processing efficiently**.

|  | **Specifications** |
|---|---|
| **Microcontroller:** ESP32 | **Flash Memory:** 4MB |
| **SRAM:** 520KB | **Frequency:** 240MHz |
| **Pins:** 22 | **Input Voltage:** 5V |
| **Current Draw (Avg):** 200mA | **Peak Current:** 500mA |
| 🔗 **[Buy Here](https://store.arduino.cc/en-ro/products/nano-esp32)** | **Function:** Controls all robot components |

---

### 🧭 Custom IMU Sensor – BMI088 

The **Custom BMI088 IMU** is used to **measure the robot's angular velocity and acceleration**, helping it maintain **stability and precise movement control**. It is essential for **calculating turns and avoiding drift**. We decided to customize it to be able to make it more compact.

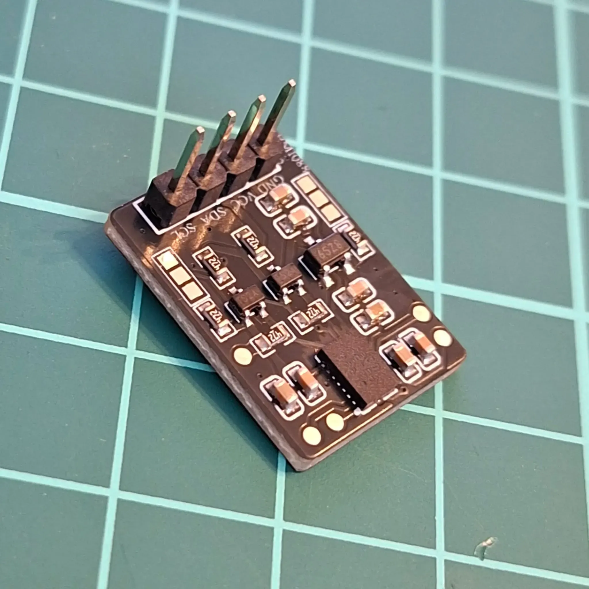
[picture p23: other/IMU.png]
|  | **Specifications** |
|---|---|
| **Gyroscope Range:** ±2000°/s | **Accelerometer Range:** ±24g |
| **Interface:** I2C | **Supply Voltage:** 3.0V – 3.6V |
| **Current Draw:** ~3.2mA | **Weight:** ~1g |
| 🔗 [View Open Source Project Here](https://oshwlab.com/bicicleta11/bmi088-gyro-module) | **Function:** Tracks orientation & motion |

---

### **📷 OpenMV RT1062 Camera – Vision Processing** <a id="openmv-rt1062-camera">

The **OpenMV Cam RT1062** handles **traffic sign recognition, lane detection, color tracking, and other visual cues** in real time. It includes its own high-performance microcontroller, so the Arduino can focus mainly on movement control while the camera processes images independently.

|  | **Specifications** |
|---|---|
| **Processor:** NXP i.MX RT1062 Cortex-M7 | **Frequency:** 600 MHz |
| **RAM:** 32 MB SDRAM + 1 MB SRAM | **Flash Memory:** 16 MB QSPI Flash |
| **Camera Sensor:** OV5640 | **Resolution:** 2592 × 1944, 5 MP |
| **Typical Vision Speed:** ~40 FPS at QVGA | **Interfaces:** UART, I2C, SPI, CAN, USB-C |
| **Connectivity:** Wi-Fi, Bluetooth 5.1, Ethernet | **I/O Voltage:** 3.3 V only |
| 🔗 **[Buy Here](https://openmv.io/collections/cameras/products/openmv-cam-rt?variant=42269003743326)** | **Function:** Detects traffic signs, lanes, and visual markers |

---

### **⚙️ Drive Motor – 30:1 Micro Metal Gearmotor HPCB 6V with Encoder** <a id="drive-motor">

The **drive motor is responsible for propelling the robot forward**. The **30:1 gearbox** provides an excellent **balance of speed and torque**, while the **built-in encoder** allows for **precise speed control**.

|  | **Specifications** |
|---|---|
| **Model:** 30:1 HPCB | **Voltage:** 6V |
| **No-load Speed:** 1000 RPM | **No-load Current:** 120mA |
| **Stall Torque:** ~0.45 kg·cm | **Stall Current:** 1.6A |
| 🔗 **[Buy Here](https://www.pololu.com/product/5184)** | **Function:** Drives the robot |

---

### **⚙️ IFX9201SG Motor Driver** 

The **IFX9201SG** motor driver is used to control the robot’s high-performance drive or impeller motor with precision and efficiency. It supports PWM-based speed control and direction control while integrating advanced protection features, making it ideal for demanding robotics applications. The IFX9201SG is directly integrated into our PCB, ensuring compact design and reliable communication with the Arduino Nano ESP32.

|  | **Specifications** |
|---|---|
| **Model:** IFX9201SG | **Operating Voltage:** 5.5V – 45V |
| **Logic Voltage:** 3.3V / 5V compatible | **PWM Frequency:** Up to 20 kHz |
| **Max Continuous Current:** 5A | **Max Peak Current:** 8A per channel |
| **Control Interface:** PWM + Direction pins | **Built-in Protections:** Overtemperature, Overcurrent, Undervoltage, Short-to-GND/Battery |
| 🔗 **[Buy Here](https://www.lcsc.com/product-image/C112633.html)** | **Function:** Controls drive motors |

---

### **🔄 Steering Servo – MG90S** <a id="steering-servo">

The **MG90S servo is used for precise steering control**, enabling the robot to **navigate turns with accuracy**. It provides **high torque output in a compact size**.

|  | **Specifications** |
|---|---|
| **Model:** MG90S | **Voltage:** 5V |
| **Torque:** 2.2kg/cm | **Signal Type:** PWM |
| **Current Draw (Avg):** 120mA | **Peak Current:** 500mA |
| **Weight:** ~13.4g | **Gears:** Plastic |
| 🔗 **[Buy Here](https://www.optimusdigital.ro/ro/motoare-servomotoare/271-servomotor-mg90s.html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)** | **Function:** Controls steering |

---

### **⚙️ Impeller for downforce** <a id="impeller">

The **impeller** generates downforce to improve the robot’s grip on the track at high speeds. Powered by a **BLDC motor**, it delivers extremely high RPM with minimal weight, making it ideal for competitive line follower and robotracer builds. Its low rotor inertia ensures instant acceleration, while the compact size allows for easy integration.

|  | **Specifications** |
|---|---|
| **Type:** BLDC Motor | **Model:** 10000KV |
| **Voltage:** 2–3S | **Shaft Diameter:** 1.0mm |
| **No-Load Speed:** ~85,000 RPM @ 7.4V	 | **	Weight:** ~4.5g |
| **Current Draw (Avg):** ~1A @ 7.4V	 | **Peak Current:** ~2.5A |
| 🔗 **[Buy Here](https://www.aliexpress.com/item/1005010313915123.html)** | **Function:** Drives the downforce impeller |

---

### **⚙️ ESC Controller for impleller** <a id="ESC">

**The EMAX D-SHOT Bullet 20A ESC controls the BLDC motor that drives the impeller. In this project, it uses a simple servo-style PWM signal, making it easy to interface with the main controller while providing smooth and reliable speed control in a compact, lightweight package.**

|  | **Specifications** |
|---|---|
| **Type:** ESC For BLDC Motors | **Model:** EMAX D-SHOT  |
| **Voltage:** 2–4S | **Protections:** Shortcircuit protection & stall protection |
| **Dimensions (LxW):** 11.9x19.6 mm	 | **Weight(W/O Wires):** ~3.5g |
| **Burst Max Current**  : ~30A	 | **Max Current:** ~20A |
| 🔗 **[Buy Here](https://emaxmodel.com/products/emax-d-shot-bullet-series-20a-2-4s-blheli_s-esc-3-5g-support-onshot42-multishot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)** | **Function:** Drives the downforce BLDC |

---

### 📏 Distance Sensor – Pololu PWM Distance Sensor 

The **Pololu Digital Distance Sensor (PW output, 300 cm max)** uses a short-range lidar module and reports distance as the width of a digital pulse (similar to a hobby-servo signal). It’s ideal for reliable, fast obstacle detection and gives you an actual distance reading (3 mm resolution), perfect for lap direction detection at start and for close-range wall sensing.

|  | **Specifications** |
|---|---|
| **Detection Range:** 300 cm (depends on surface) | **Type:** Digital pulse width (HIGH-time encodes distance) |
| **Voltage Supply:** 3.0V – 5.5V | **Current Draw:** ~30 mA enabled, ~0.4 mA disabled (EN low) |
| **Resolution:** 3 mm (≈ 4 µs per 3 mm)	 | **Update Rate:** ~50–110 Hz (period ~20–9 ms) |
| **Dimensions:** 21.6mm × 8.9mm × 3.1mm | **Weight:** 1g |
| 🔗 [Buy Here](https://www.pololu.com/product/4064) | **Use Case:** Start-line lap direction & close-range obstacle sensing for parking |

Here is the positioning and viewing angle of the sensors. 



---

### **🔌 D24V50F5 Voltage Regulator – Power Management** <a id="voltage-regulator"> 

The **D24V50F5** regulates the **7.4V Li-Po battery output** to a **stable 5V**, ensuring **safe power delivery** to the **Arduino, sensors, and camera**. It prevents **overvoltage damage** and includes **thermal & short-circuit protection** for reliability.

|   | **Specifications** |
|---|---|
| **Model:** D24V50F5 | **Input Voltage:** 6V – 38V |
| **Output Voltage:** 5V | **Output Current:** 5A |
| **Efficiency:** Buck Converter (Step-down) | **Dropout Voltage:** ~2V |
| **Protection:** Short-circuit & thermal shutdown | **Mounting Type:** Pins |
| 🔗 **[Buy Here](https://www.pololu.com/product/2851)** | **Function:** Converts battery voltage to 5V |

---

### **🛠️ PCB Design & Electrical Architecture** 

| **Electrical Schematics** | **PCB Copper Traces** | **Final PCB Chassis** |
|---|---|---|
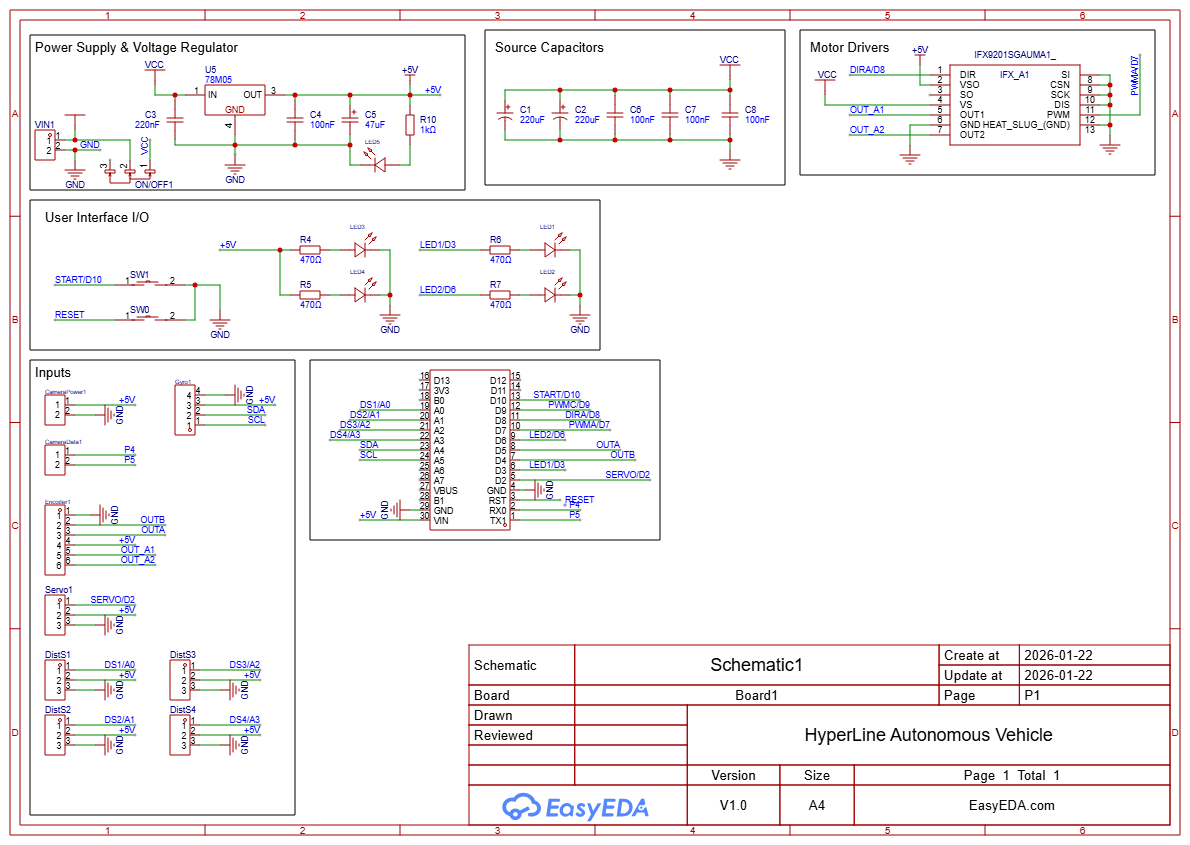
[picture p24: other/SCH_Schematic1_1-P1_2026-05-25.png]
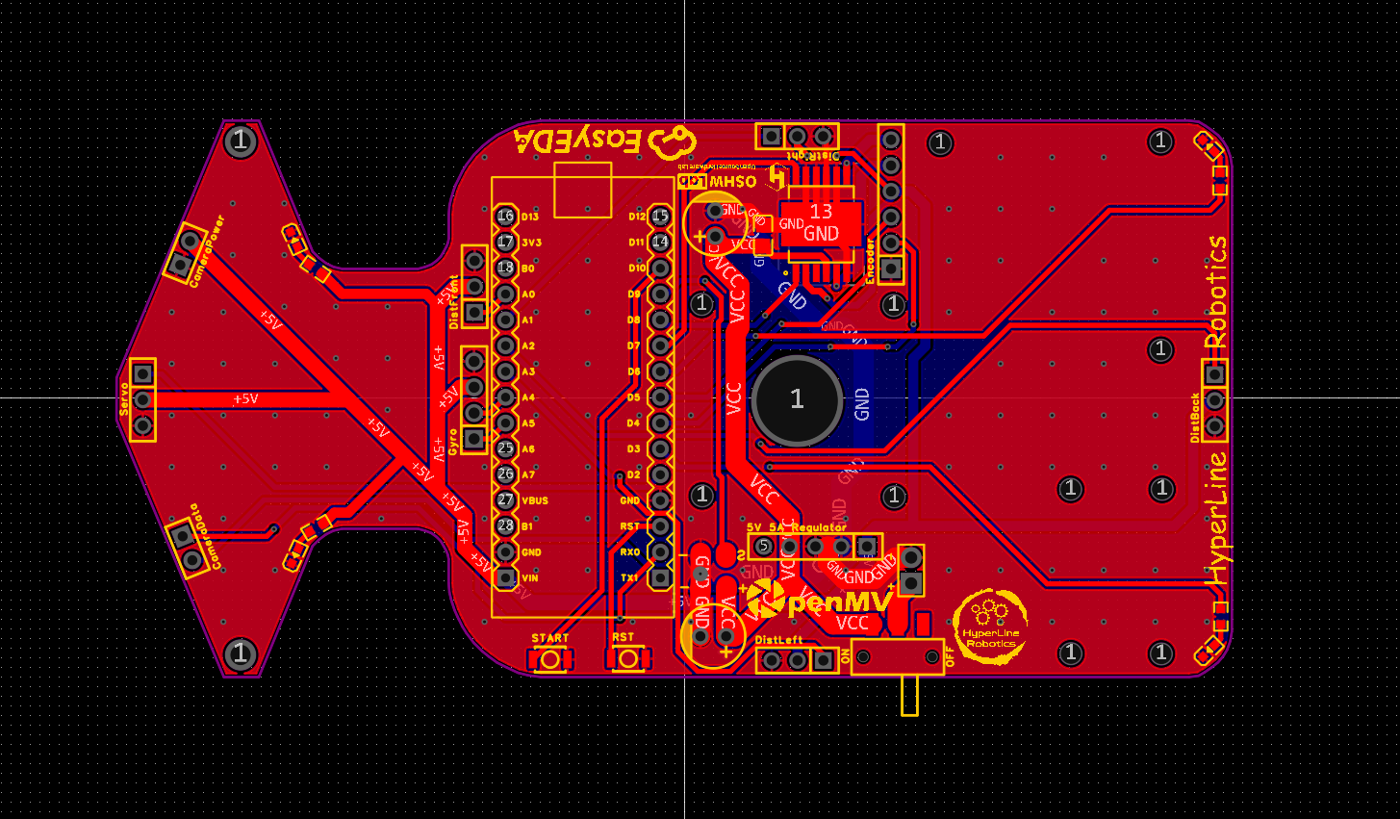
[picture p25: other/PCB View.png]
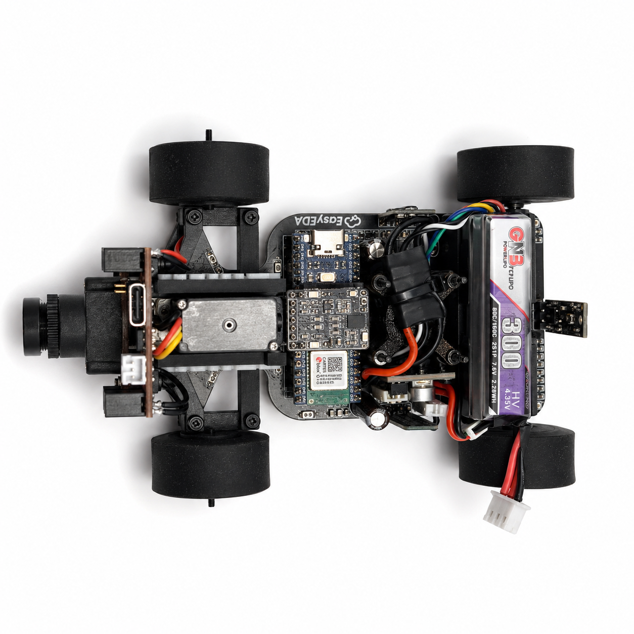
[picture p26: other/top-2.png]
|  |  |  |

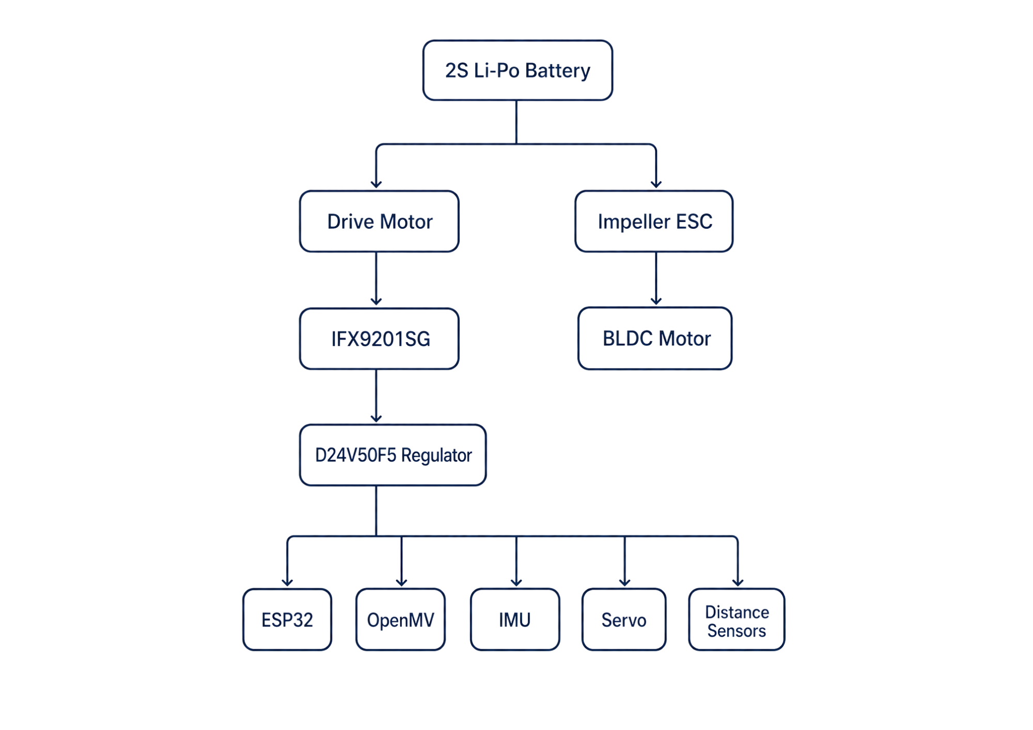
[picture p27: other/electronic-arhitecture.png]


The robot uses a fully custom PCB chassis designed to combine both the electrical system and the structural frame into a single compact platform. This approach reduced weight, improved rigidity, and increased overall reliability during high-speed autonomous runs.

### **Advantages of the Custom PCB Chassis**
- Cleaner construction with fewer wires and connectors  
- More stable power delivery for motors and sensors  
- Better reliability during high-speed runs  
- Compact design with improved weight distribution  
- Reduced electrical interference on communication lines  
- Stronger and more rigid compared to multi-part printed structures

### **🔧 Engineering Decisions**
The PCB was designed with separated high-current and logic-power areas to reduce electrical noise generated by the motors and impeller system. Large copper pours were also used to improve current handling and passive heat dissipation.

Several PCB revisions were tested before the final version, improving:
- Motor power routing
- Sensor stability
- Weight distribution
- Connector accessibility
- Mechanical resistance

---

### **⚡ Power Consumption Summary** 

| Item / Designators | Part | Supply | Typical Current | Peak Current | Notes |
|---|---|---|---|---|---|
| Main Controller | Arduino Nano ESP32 | 5V | ~200mA | ~500mA | Main processing unit |
| Vision Processing | OpenMV Cam RT1062 | 5V | ~300mA | ~500mA | Traffic sign & lane detection |
| Gyroscope / IMU | Custom BMI088 Module | 3.3V | ~3.2mA | ~5mA | Orientation and angular velocity |
| Drive Motor | Pololu 30:1 HPCB Gearmotor | 6V | ~120mA | ~1.6A | Peak occurs during acceleration/stall |
| Steering System | MG90S Servo | 5V | ~120mA | ~500mA | High peaks during fast steering |
| Downforce System | 10000KV BLDC Impeller + ESC | 7.4V | ~1.5A | ~4A | Generates aerodynamic downforce |
| Distance Sensor #1 | Pololu PWM Distance Sensor | 5V | ~30mA | ~35mA | Front obstacle detection |
| Distance Sensor #2 | Pololu PWM Distance Sensor | 5V | ~30mA | ~35mA | Side obstacle detection |
| Motor Driver | IFX9201SG | 5V Logic / VBAT | ~10mA | ~20mA | Logic current only |
| Voltage Regulator | D24V50F5 | 7.4V → 5V | Depends on load | Depends on load | Powers 5V electronics |
| Total Estimated Consumption | Entire Robot | 7.4V Battery | ~2.3A | ~7A | Worst-case peaks during acceleration |

The robot was designed with power efficiency and peak-current stability in mind. High-current systems such as the impeller and drive motor are electrically separated from sensitive logic components to reduce electrical noise and voltage drops during acceleration. Large copper pours and short power paths on the PCB help improve current handling and thermal dissipation.

---

## 🔋 Power and Sensor Validation  

To make sure that the robot is reliable during a full run, we tested the complete power system under several operating conditions. The robot uses a 2S Li-Po battery as the main power source. The drive motor and impeller are powered from the battery side, while the logic electronics are powered through the D24V50F5 5V regulator.

The goal of this architecture is to separate high-current discharge loads from sensitive logic components such as the ESP32, OpenMV camera, IMU, and distance sensors. This reduces the risk of voltage drops, camera resets, IMU instability, and wrong sensor readings during acceleration or steering corrections.

| Test condition | 5V rail measured value | Result |
|---|---:|---|
| Robot idle, electronics only | 5.03V | Stable |
| Servo moving left/right continuously | 4.96V | No ESP32 reset |
| Camera running with UART active | 5.00V | Stable image processing |
| Drive motor accelerating | 4.92V | No brownout |
| Impeller ramping up | 4.89V | No ESC reset |
| Full system active during driving | 4.87V to 5.05V | Stable |

The lowest measured voltage on the 5V rail was above the safe operating range for the ESP32, OpenMV, IMU, and sensors. During testing, no controller reset was observed. This confirms that the regulator has enough current margin for the logic side of the robot. We also tested the robot with the impeller starting instantly and with ramp-up. Instant start produced larger voltage drops and mechanical instability, so we used a controlled ramp-up in software. This gives the robot smoother acceleration and avoids sudden current spikes.

### ⚠️ Power failure points and mitigation 

| Possible failure | Cause | Mitigation |
|---|---|---|
| ESP32 reset | 5V voltage drop during motor acceleration | Logic powered through D24V50F5 regulator |
| Camera frame instability | Electrical noise or unstable supply | Separate regulated 5V line and common ground |
| Servo jitter | Current peaks during steering | Short power path and stable regulator output |
| Wrong distance readings | Voltage fluctuation or sensor noise | Sensor filtering and repeated readings |
| Impeller current spike | BLDC startup load | Software ramp-up instead of instant full power |

This testing showed that the power architecture is reliable under realistic competition loads.

---

## 💻 Components coding 

### 🧠 Software Architecture 

This diagram below, shows how the main software modules interact during a run. The OpenMV RT1062 handles image processing and sends compact commands through UART, while the Arduino Nano ESP32 manages motion control, state logic, steering, motor speed, and parking.

The software is split into independent modules so each subsystem can be tested separately. Vision data is used by the obstacle and parking logic, while the gyro PID keeps the robot stable between decisions. Final movement commands are sent to the steering servo and IFX9201SG motor driver.
7
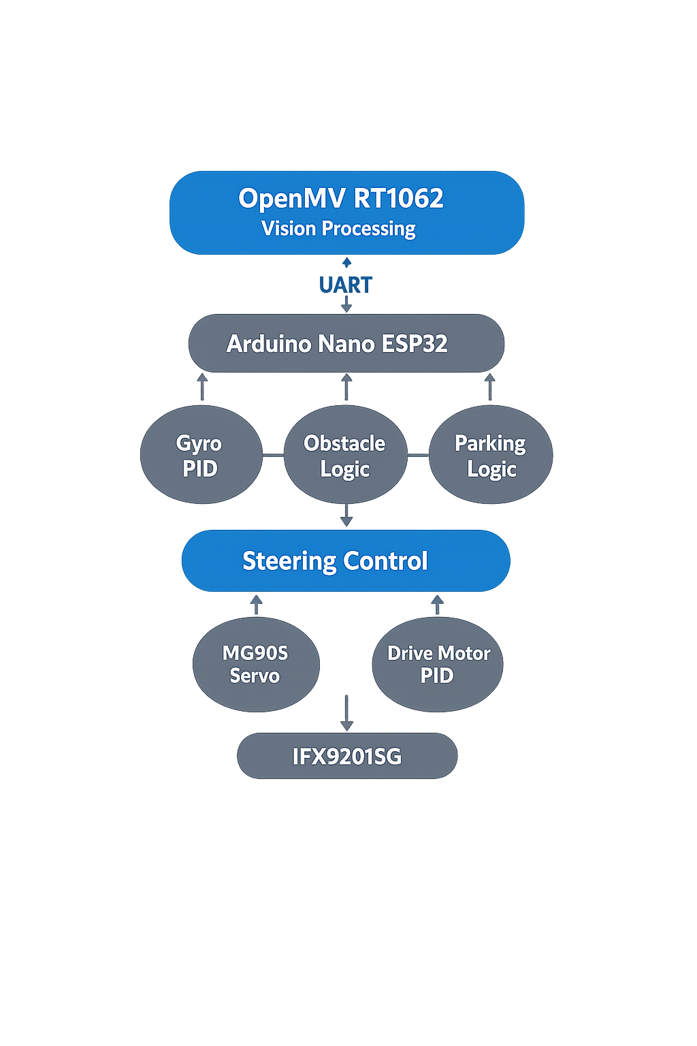
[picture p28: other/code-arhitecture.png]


### 🔄 Robot State Machine 

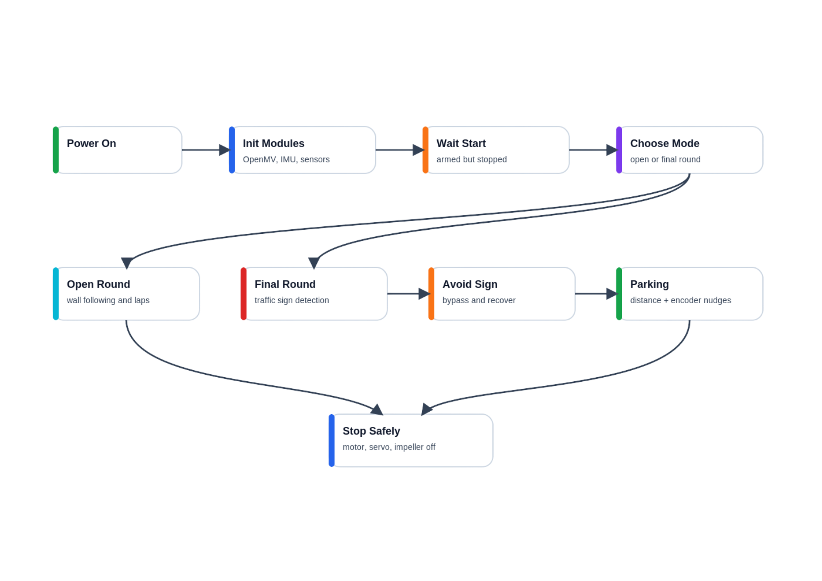
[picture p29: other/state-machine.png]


The robot software is organized as a state machine. Each state has a specific role, and transitions happen only when a clear sensor event or timing condition is detected. This makes the robot easier to debug, safer during runs, and more reliable in the randomized WRO track.

| State | Purpose | Main Inputs | Output |
|---|---|---|---|
| `WAIT_START` | Keeps the robot stopped before the round begins | Start button | Starts autonomous run |
| `PID_DRIVE` | Drives straight using gyro-based PD correction | Gyro, camera line/wall signals | Steering + motor speed |
| `FOLLOW_CUBE` | Follows the detected red/green cube before avoidance | OpenMV `S±value` command | Servo correction toward cube |
| `AVOID_CUBE` | Passes the cube on the correct side based on color | OpenMV `RED` / `GREEN` command | Fixed avoidance maneuver |
| `AFTER_CUBE` | Realigns the robot after avoiding a cube | Gyro angle, timeout | Returns to stable driving |
| `TURN_90` | Performs a 90° turn when a corner is detected | Black wall signal, turn direction | Updates target gyro angle |
| `PARKING` | Executes the final parallel parking routine | Distance sensors, gyro | Parks inside the parking area |
| `STOP` | Ends the run safely | Parking complete | Motor off, steering centered |

Some behaviors shown in the high-level software diagram are not implemented as separate `RobotState` enum values because they are simple control phases, not long-running robot modes. For example, the start procedure is implemented as a blocking wait before the main loop starts:
```cpp
while (digitalRead(START_BUTTON) == HIGH) {
  // wait for start signal
}
```

Using a state machine prevents different behaviors from interfering with each other. For example, while the robot is parking, camera commands are ignored, and while it is avoiding a cube, the normal driving PID is temporarily paused. This makes the behavior more predictable and easier to test during repeated runs.

### ⚡ Drive motor 

The motor driver is based on the **Infineon IFX9201SG**, which allows us to directly manage the motor with only two control signals: a **PWM** pin that regulates speed, and a direction pin that selects forward or reverse rotation. Thanks to this chip’s integrated design, no external library was required for motor control.

We implemented a set of functions within our control system: one to initialize the driver, one to control motor velocity, and another to stop it effectively using an active braking routine. The function **move(int speed)** takes an input in the range **−255** to **+255**. The absolute value of the input is written to the **PWM channel**, while the sign determines the motor’s rotation direction. A dedicated **stop_motor()** function applies a short reverse torque pulse before setting the PWM duty cycle to zero, ensuring the robot stops quickly without uncontrolled coasting.

Since the robot is powered by an **ESP32**, **PWM** signals must be generated using the **LEDC** hardware utility, which provides stable and precise duty cycles.

```cpp
void motor_driver_setup() {
  pinMode(PWMA, OUTPUT);
  pinMode(DIRA, OUTPUT);
  ledcSetup(PWM_MOTOR_CHANNEL, PWM_MOTOR_FREQ, PWM_MOTOR_RESOLUTION);
  ledcAttachPin(PWMA, PWM_MOTOR_CHANNEL);
  move(0);
}

void move(int speed) {
  ledcWrite(PWM_MOTOR_CHANNEL, abs(speed));
  digitalWrite(DIRA, speed > 0 ? LOW : HIGH);
}

void stop_motor() {
  move(-3);
  delay(100);
  move(0);
}
```

For odometry, the motor includes an encoder. We implemented an interrupt-based approach to count ticks in real time, avoiding the need for a dedicated library. The encoder setup attaches an interrupt on the rising edge of channel A, and the distance traveled is computed from tick counts.

In this configuration, the encoder provides 12 counts per revolution, and by applying the gear ratio, wheel diameter, and π, we obtain a conversion factor of `MM_PER_TICK = 1.8326`. This enables the robot to measure traveled distance with centimeter-level accuracy, which is crucial for precise maneuvers during navigation.

```cpp
void encoder_setup() {
  // Enable pull-ups so A/B never float
  pinMode(ENCODER_A, INPUT_PULLUP);
  pinMode(ENCODER_B, INPUT_PULLUP);
  // Attach only A’s rising edge:
  attachInterrupt(digitalPinToInterrupt(ENCODER_A), encoderISR, RISING);
  encoder_ticks = 0;
}

float read_cm() {
  noInterrupts();
  int32_t t = encoder_ticks;
  interrupts();

  float dist_mm = t * MM_PER_TICK;
  float dist_cm = dist_mm / 10.0f;
  //Serial.printf("ticks=%ld  dist_cm=%.2f\n", t, dist_cm);
  return dist_cm;
}
```

### 🌪️ Impeller 

The impeller is responsible for generating downforce, which increases stability and traction when the robot operates at high speed. To control it, we use an **EMAX BULLET ESC**, wired as a low-side switch. This **ESC** can safely handle the high current required by the impeller, while allowing speed control via **PWM** modulation.

Only a single PWM pin from the ESP32 is needed to drive the ESC. The PWM duty cycle determines how much power is applied to the impeller:

```
0 = off
255 = full speed
```

Two functions were implemented for simplicity: one for initializing the PWM channel and one for setting the impeller speed.

```cpp
void impeller_setup() {
  pinMode(PWM_IMPELLER, OUTPUT);
  ledcSetup(PWM_IMPELLER_CHANNEL, PWM_IMPELLER_FREQ, PWM_IMPELLER_RESOLUTION);
  ledcAttachPin(PWM_IMPELLER, PWM_IMPELLER_CHANNEL);
}

void setImpeller(int _pwm) {
  ledcWrite(PWM_IMPELLER_CHANNEL, constrain(_pwm, 0, 255));
}
```

### 🎮 Servo motor 

The steering system is controlled by a **MG90S servo**, which adjusts the angle of the front wheels. This enables the robot to follow precise paths while maintaining stability during turns.

The servo is connected directly to the **ESP32** and driven using the `ESP32Servo.h` library interface. To ensure consistent and safe motion, we defined three reference positions:

```
STEERING_LEFT = 140
STEERING_CENTER = 85
STEERING_RIGHT = 40
```

These values were experimentally calibrated to match the geometry of the steering mechanism.

The function `steering_servo_setup()` attaches the servo to its pin, performs a left–right sweep to verify operation, and finally centers it. This ensures that the robot always starts in a straight-line configuration.

The function `steer(double steering_angle)` accepts an input in the range `[-1, 1]`, representing normalized steering:

```
-1 = maximum right
0 = centered
+1 = maximum left
```

The input is first clamped to stay within the allowed range, then mapped to the calibrated servo values using **map_double**. This abstraction allows higher-level controllers (such as PID) to provide normalized outputs without directly worrying about servo limits.

```cpp
void steering_servo_setup() {
  steeringServo.attach(STEERING_SERVO);
  delay(100);

  steeringServo.write(STEERING_LEFT);
  delay(300);
  steeringServo.write(STEERING_RIGHT);
  delay(300);
  steeringServo.write(STEERING_CENTER);
  delay(300);
}

void steer(double steering_angle) {
  // Clamp input between -1 and 1
  if (steering_angle > 1)  steering_angle = 1;
  if (steering_angle < -1) steering_angle = -1;

  // Map to servo range
  steering_angle = map_double(steering_angle, -1, 1, STEERING_LEFT, STEERING_RIGHT);
  steeringServo.write(steering_angle);
}
```

### 🧭 IMU 

To keep the robot on a straight path and execute precise turns, we rely on the **Bosch BMI088 Inertial Measurement Unit (IMU)**. This sensor combines a high-resolution accelerometer and gyroscope, and in our case we primarily use the **Z-axis** gyroscope for yaw angle estimation.

During initialization, the function `gyro_setup()` configures the BMI088 via **I²C** communication. The accelerometer is set to a **±6 g** range at **200 Hz**, while the gyroscope is set to **±2000 °/s** at **400 Hz** with a **47 Hz bandwidth**. These parameters provide a good balance between responsiveness and noise filtering.

A key challenge with gyroscopes is drift — the tendency of small measurement errors to accumulate over time. To correct this, the setup function performs a calibration routine: for a predefined duration **(DRIFT_TEST_TIME)**, the sensor’s output is averaged while the robot is stationary. The resulting bias **(drifts_z)** is subtracted from all subsequent readings.

```cpp
void gyro_setup() {
  // 1) Wire + basic init
  Wire.begin();
  imu.initialize();

  imu.setAccScaleRange(RANGE_6G);
  imu.setAccOutputDataRate(ODR_200);       // 200 Hz accel
  imu.setAccPoweMode(ACC_ACTIVE);

  imu.setGyroScaleRange(RANGE_2000);
  imu.setGyroOutputDataRate(ODR_400_BW_47); // 400 Hz, BW=47 Hz
  imu.setGyroPoweMode(GYRO_NORMAL);

  if (!imu.isConnection()) {
    if (debugGyro) {
      Serial.println("BMI088 connection failed!");
    }
    return;
  }

  if (debugGyro) Serial.println("Starting gyro drift calculation...");
  double start = millis();
  gyro_last_read_time = start;
  gz = 0;

  while (millis() - start < DRIFT_TEST_TIME * 1000) {
    double now = millis();
    double dt = (now - gyro_last_read_time) * 0.001; // s
    float rate = imu.getGyroscopeZ();                // °/s
    gz += rate * dt;                                 // accumulate degrees
    gyro_last_read_time = now;
  }

  drifts_z = gz / DRIFT_TEST_TIME;  // average °/s
  if (debugGyro) {
    Serial.print("Drift test done! drifts_z = ");
    Serial.print(drifts_z, 6);
    Serial.println(" °/s");
  }

  // reset integration
  gz = 0;
  gyro_last_read_time = millis();
} 
```

The function `read_gyro_data()` must be called continuously in the control loop. It computes the elapsed time **dt**, reads the current angular rate from the **BMI088**, subtracts the drift offset, and integrates the result into **gz**, which represents the robot’s absolute yaw angle in degrees. This value is used directly in the **PID controller** for heading correction.

```cpp
void read_gyro_data() {
  // call this frequently (e.g. every loop)
  double now = millis();
  double dt  = (now - gyro_last_read_time) * 0.001; // s          
  float rate = imu.getGyroscopeZ();              // °/s
  double corrected = rate - drifts_z;               // drift-compensated
  gz += corrected * dt;                             // integrate to degrees
  gyro_last_read_time = now;

  if (debugGyro) {
    Serial.print("Gyro angle (°): ");
    Serial.println(gz, 4);
  }
}
```

### 📡 Distance sensors 

The robot integrates four **Pololu PWM distance sensors**, placed on the **front, back, left, and right sides** of the chassis. Each sensor outputs a pulse width signal, where the duration is proportional to the measured distance. This gives us precise range data without requiring complex communication protocols.

The function `distanceSensorPin(DistanceDir d)` maps each logical direction (FRONT_DIR, LEFT_DIR, RIGHT_DIR, BACK_DIR) to its corresponding analog pin. Using `pulseIn()`, we measure the pulse width, and the helper function `pulseToMM()` converts it into millimeters based on the calibration constants:

```
PW_OFFSET_US – offset at ~0 mm (typically ~1000 µs)
PW_US_PER_MM – scaling factor (1 µs per mm)
PULSE_TIMEOUT_US – maximum waiting time for a valid pulse (30 ms)
```

If no valid pulse is received, the function returns **-1** to indicate a timeout.

```cpp
// ======= Pololu PWM Distance Sensor Settings =======
static const float PW_OFFSET_US   = 1000.0f; // microseconds offset at ~0 mm
static const float PW_US_PER_MM   = 1.0f;    // microseconds per millimeter
static const unsigned long PULSE_TIMEOUT_US = 30000UL; // 30 ms timeout

// ======= Map direction to the correct pin =======
static inline int distanceSensorPin(DistanceDir d) {
  switch (d) {
    case FRONT_DIR: return PWM_DIST_FRONT; // A0
    case LEFT_DIR:  return PWM_DIST_LEFT;  // A3
    case RIGHT_DIR: return PWM_DIST_RIGHT; // A1
    case BACK_DIR:  return PWM_DIST_BACK;  // A2
  }
  return PWM_DIST_FRONT;
}

// ======= Read pulse in microseconds =======
static inline unsigned long readPulseUS(int pin) {
  pinMode(pin, INPUT);
  return pulseIn(pin, HIGH, PULSE_TIMEOUT_US);
}

// ======= Convert pulse width to millimeters =======
static inline float pulseToMM(unsigned long pw_us) {
  if (pw_us == 0) return -1.0f; // timeout
  float mm = (float(pw_us) - PW_OFFSET_US) / PW_US_PER_MM;
  if (mm < 0) mm = 0;
  return mm;
}
```

Below you can see where the laser sensors and camera view fields are:



### 📷 Camera 

Once the robot can move and steer, it also needs to see and react to the environment. For this, we use an **OpenMV camera module**, connected via **UART protocol**. This allows the camera to handle the heavy work of image processing and only send compact messages (like colors, cubes, or angles) to the **ESP32**.

The camera is wired to the **ESP32** as follows:
- Camera TX (P4) → ESP32 RX (D0)
- Camera RX (P5) → ESP32 TX (D1)

Both devices must share the same baud rate **(19200)**. On the **ESP32** side, we use `Serial0` for communication, while on the camera side, `UART(3, 19200)` is initialized.

**Arduino code:**

```cpp
// UART to OpenMV (SoftwareSerial on D0/D1)
String receivedMessage;

void comm_setup() {
  Serial.begin(9600);
  Serial0.begin(19200);          // must match OpenMV baudrate
  receivedMessage = "";
  // (optional) small flush
  while (Serial0.available()) Serial0.read();
}

void loop() {
  // ... control loop stuff ...

  // Execute pending commands from camera
  while (Serial0.available() > 0) {
    char c = Serial0.read();
    if (c == '\n') {
      // Optionally skip commands while parking
      if (CASE != PARK) {
        execute_command(receivedMessage); // handle "S<angle>", "BLUE", "ORANGE", "RED", "GREEN", "BLACK", "1", "2"
      }
      receivedMessage = "";
    } else {
      receivedMessage += c;
    }
  }
}
```

**Camera code:**

We use `UART(3, 19200)` on **OpenMV (P4=TX, P5=RX)**. Baud must match the Arduino side.

```python
from pyb import UART
uart = UART(3, 19200)
# 3 → uses P4 (TX) and P5 (RX)
# 19200 → baud rate, must match Arduino
```

Arduino listens and executes messages line-by-line (ending with `\n`). Camera only sends.

We configure the camera for `RGB565, QVGA (320×240)`, flipped to match mounting, and fixed exposure/gain/WB for consistent LAB thresholds.

```python
import sensor
import time
from machine import UART, LED

# -------- DEBUG FLAG --------
DEBUG = False

# -------- Camera & Sensor Setup --------
sensor.reset()
sensor.set_pixformat(sensor.RGB565)
sensor.set_framesize(sensor.QVGA)       # QVGA: 320x240

sensor.set_vflip(True)
sensor.set_hmirror(True)

# Disable auto settings for stable color tracking.
# RT1062 uses the OV5640 sensor, so you may need to retune thresholds/exposure.
sensor.set_auto_gain(False)
sensor.set_auto_whitebal(False)
sensor.set_auto_exposure(False, exposure_us=16000)

sensor.skip_frames(time=2000)
clock = time.clock()
```

Why fixed exposure? It keeps color thresholds stable across frames and lighting.

Color thresholds **(LAB)** for red/green cubes, blue/orange lines, black walls.
We also define ROIs to look only where each object should appear (faster + fewer false positives).

```python
# ---- LAB thresholds ----
red_threshold    = [(32, 54, 40, 67, 17, 63)]
green_threshold  = [(36, 69, -56, -21, -19, 32)]
blue_threshold   = [(9, 76, -45, 27, -57, -8)]
orange_threshold = [(62, 91, -3, 43, 5, 69)]
pink_threshold   = [(30, 70, 10, 60, -15, 15)]
black_threshold  = [(0, 37, -26, 7, -17, 11)]

# ---- Regions of Interest ----
img_h, img_w = sensor.height(), sensor.width()
cubes_roi      = (0, int(img_h * 0.4),  img_w,        int(img_h * 0.6))  # bottom area
lines_roi      = (5, int(img_h * 0.5),  img_w - 10,   int(img_h * 0.4))  # lower band
wall_roi       = (50, int(img_h * 0.5 - 18), img_w - 100, int(img_h * 0.2 - 10))
final_wall_roi = (30, 80, img_w - 60, int(img_h - 60))
```

Minimum areas to reject noise and a simple **PD** setup for cube following.

```python
min_cube_size       = 300
min_line_size       = 800
min_area            = 10
min_valid_cube_area = 450
black_wall_min_area = 7000
final_black_wall_min_area = 9000
min_black_height    = 39

kp_cube = 0.21
kd_cube = 2.4
pid_error = 0.0
pid_last_error = 0.0
follow_threshold = 4100

direction = 0  # 0 = unset, 1 = LEFT(blue), 2 = RIGHT(orange)

def get_largest_blob(blobs):
    return max(blobs, key=lambda b: b.area(), default=None)
```

Every frame, we:
- Detect walls (parking / turn signal) → send `"BLACK"`
- Detect cubes (red/green) → send `S<error>` for follow, or `RED/GREEN` when very close
- Detect lines (blue/orange) → send `"BLUE"/"ORANGE"` and set direction (1/2)
- Always send the current direction **("1"/"2")** for sync

```python
while True:
    clock.tick()
    img = sensor.snapshot()
    target_x = img_w // 2

    # ---- Walls / parking ----
    black_blobs = img.find_blobs(black_threshold, roi=final_wall_roi,
                                 pixels_threshold=final_black_wall_min_area,
                                 area_threshold=final_black_wall_min_area, merge=True)
    black_blob = get_largest_blob(black_blobs)
    if black_blob and black_blob.h() >= min_black_height:
        uart.write("BLACK\n")

    # ---- Cubes (red/green) ----
    red_blobs   = img.find_blobs(red_threshold,   roi=cubes_roi,
                                 pixels_threshold=min_cube_size,
                                 area_threshold=min_cube_size, merge=True)
    green_blobs = img.find_blobs(green_threshold, roi=cubes_roi,
                                 pixels_threshold=min_cube_size,
                                 area_threshold=min_cube_size, merge=True)

    red_cube   = get_largest_blob([b for b in red_blobs   if b.area() >= min_valid_cube_area])
    green_cube = get_largest_blob([b for b in green_blobs if b.area() >= min_valid_cube_area])

    candidates = []
    if red_cube:   candidates.append(('RED',   red_cube))
    if green_cube: candidates.append(('GREEN', green_cube))

    if candidates:
        color, cube = max(candidates, key=lambda x: x[1].area())
        # normalized horizontal error in [-1..1]
        error = (cube.cx() - target_x) / float(target_x)
        pid_error = kp_cube * error + kd_cube * (error - pid_last_error)
        pid_last_error = error

        if cube.area() < follow_threshold:
            uart.write("S{:+.3f}\n".format(error))   # steer hint for FOLLOW_CUBE
        else:
            uart.write(color + "\n")                 # close: just report color

    # ---- Lines (blue/orange) ----
    blue_blobs   = img.find_blobs(blue_threshold,   roi=lines_roi,
                                  pixels_threshold=min_line_size,
                                  area_threshold=min_line_size, merge=True)
    orange_blobs = img.find_blobs(orange_threshold, roi=lines_roi,
                                  pixels_threshold=min_line_size,
                                  area_threshold=min_line_size, merge=True)

    blue_line   = get_largest_blob([b for b in blue_blobs])
    orange_line = get_largest_blob([b for b in orange_blobs])

    chosen = None
    if blue_line and orange_line:
        chosen = "BLUE" if blue_line.area() > orange_line.area() else "ORANGE"
    elif blue_line:
        chosen = "BLUE"
    elif orange_line:
        chosen = "ORANGE"

    if chosen:
        uart.write(chosen + "\n")
        if direction == 0:
            direction = 1 if chosen == "BLUE" else 2

    # ---- Always send current turn direction ----
    uart.write(str(direction) + "\n")
```

---

## 📝 Obstacle Management 

### 🏁 Open Round 
During the **Open Round**, our robot follows a **straight trajectory using a PID controller based on gyro yaw**, ensuring stable movement. To determine turns, the **camera detects Orange and Blue lines** on the track:
- **Orange Line ➜ Right Turn**
- **Blue Line ➜ Left Turn**
- The turn is executed when the robot reaches an approximate **distance from the front black wall**.

#### **Camera Processing for Line Detection**
The camera captures frames in **RGB565** format and processes color blobs using **LAB thresholds** to detect relevant track elements. Below is a **snippet of the camera’s core logic** that identifies **track lines and determines turning direction**:

```python
# Detect Blobs
red_blobs = img.find_blobs(red_threshold, roi=cubes_roi, pixels_threshold=min_cube_size, area_threshold=min_cube_size, merge=True)
green_blobs = img.find_blobs(green_threshold, roi=cubes_roi, pixels_threshold=min_cube_size, area_threshold=min_cube_size, merge=True)
blue_blobs = img.find_blobs(blue_threshold, roi=lines_roi, pixels_threshold=min_line_size, area_threshold=min_line_size, merge=True)
orange_blobs = img.find_blobs(orange_threshold, roi=lines_roi, pixels_threshold=min_line_size, area_threshold=min_line_size, merge=True)
black_blobs = img.find_blobs(black_threshold, roi=cubes_roi, pixels_threshold=min_cube_size, area_threshold=min_cube_size, merge=True)

...

# Determine Direction
if direction == 0:
    if orange_line and not is_invalid_orange(orange_line, red_blobs):
        direction = 2  # Orange line first ➜ turn right
    elif blue_line:
        direction = 1  # Blue line first ➜ turn left

# Send Direction Command
uart.write(str(direction) + '\n')
```

### ⚡ Final Round 

In the final round, we extend our open rount algorithm by adding real‐time cube detection, following, and avoidance algorithms. The OpenMV RT1062 camera handles live frames processing and sends compact UART messages to the Arduino Nano ESP32. On the Arduino, incoming UART messages drive a four‐state algorithm: in **PID**, the robot adjust to hold a straight heading by using a PD on the gyro and turns 90° whenever it receives a **BLACK** signal (lap turning point in each corner). In **FOLLOW_CUBE**, the camera’s **S<corrected_servo>** message directly sets the servo angle to chase the closest visible cube; if no follow message arrives within 250-500 ms, it returns to **PID** as the cube might have been passed or lost from the view. When a proximity trigger (**RED** or **GREEN**, **R** or **G**) arrives, it switches to **AVOID_CUBE**, executes a 37° turn plus an 8 cm clear‐away while holding that heading, then enters **AFTER_CUBE** to reallign on gyro while moving back to center section of each side of the map, and to flush the leftover commands before reverting to **PID**.

**Final Round Flowchart:**
```txt
Detect Cube
     ↓
Determine Color
     ↓
Follow Cube
     ↓
Avoid Left/Right
     ↓
Recenter Robot
     ↓
Return To PID
```
---

### Arduino Side

#### States Driving Logic

This `switch` statement runs inside `void loop()` and decides what the robot does in each of the four states.

```cpp
switch (currentState) {

  case PID:
    {
      // PID straight‐drive, maintain heading using gyro PD
      double err = current_angle_gyro - gz;
      pid_error        = (err) * kp + (pid_error - pid_last_error) * kd;
      pid_last_error   = pid_error;
      steer(pid_error);
      move(robot_speed);
      break;
    }

  case FOLLOW_CUBE:
    {
      // If no follow command arrives within 250-500ms, go back to gyro PD
      if (millis() - last_follow_cube > FOLLOW_CUBE_LOST_TIME) {
        currentState = PID;
      }
      // Otherwise, steer directly toward the cube, so we do active cube following, using a PD that runs on the camera
      steer(follow_cube_angle);
      move(robot_speed);
      break;
    }

  case AVOID_CUBE:
    {
      // Perform the hard coded avoidance maneuver
      pass_cube(cube_avoid_direction);
      break;
    }

  case AFTER_CUBE:
    {
      // Return to PID after getting to be straight again, while ignoring all commands
      while (millis() - last_cube_time > 1500) {
        read_gyro_data();
        double error = current_angle_gyro - gz;
        pid_error = (error)*kp + (pid_error - pid_last_error) * kd;
        pid_last_error = pid_error;
        if (debug == true) {
          Serial.print(current_angle_gyro);
          Serial.print("     |      ");
          Serial.print(turn_direction);
          Serial.print("     |      ");
          Serial.print(gz);
          Serial.print("     |      ");
          Serial.println(robot_speed);
        }
        steer(pid_error);
        move(robot_speed);
      }
      currentState = PID;
      Serial0.flush();
      break;
    }
}
```

**PID:**
- Uses a PD loop on the integrated gyro yaw (`gz`) vs. desired heading (`current_angle_gyro`).
- Calls `steer(pid_error)` and `move(robot_speed)` to drive straight.

**FOLLOW_CUBE:**
- If we haven’t received a new `"S…\n"` follow message for at least 250-500 ms, assume the cube is lost or passed and switch back to **PID**.
- Otherwise, use `follow_cube_angle` (sent by the camera) to set the servo and follow the cube.

**AVOID_CUBE:**
- Calls `pass_cube(cube_avoid_direction)`, which executes a turn to left or right based on the cube color. This code sequence is hard coded.
  
**AFTER_CUBE:**
- Return to **PID** after getting to be straight again, while ignoring all commands.

 #### UART Command Parser (execute_command())
 
This function is called whenever a complete line arrives over **UART**. It selects which state to enter (**PID**, **FOLLOW_CUBE**, **AVOID_CUBE**) or adjusts gyro target angle on a **BLACK** message by adding or removing 90 degrees, based on the turn direction.

```cpp
void execute_command(String cmd) {
  cmd.trim();
  cmd.toUpperCase();

  // “S…” steering to follow cube ➜ FOLLOW_CUBE
  if (cmd.startsWith("S") && RUN_MODE == 1) {
    float val = cmd.substring(1).toFloat();
    follow_cube_angle = val;
    currentState      = FOLLOW_CUBE;
    last_follow_cube  = millis();

    if (debug) {
      Serial.print("FOLLOW_CUBE angle ➜ ");
      Serial.println(follow_cube_angle);
    }
    return;
  }

  // Map color words to one letter commands and set turn_direction on first BLUE/ORANGE
  char c = cmd.charAt(0);
  if      (cmd.indexOf("BLACK")  != -1) { c = 'B'; }
  else if (cmd.indexOf("BLUE")   != -1) { c = 'L'; lastLineDetectedTime = millis(); if (turn_direction == 0) turn_direction = -1; }
  else if (cmd.indexOf("ORANGE") != -1) { c = 'O'; lastLineDetectedTime = millis(); if (turn_direction == 0) turn_direction =  1; }
  else if (cmd.indexOf("RED")    != -1) { c = 'R'; }
  else if (cmd.indexOf("GREEN")  != -1) { c = 'G'; }
  else if (cmd.indexOf("PINK")   != -1) { c = 'P'; }
  else { return; }  // Ignore any other strings

  // “BLACK” turn 90° if in PID
  if (currentState == PID) {
    if (c == 'B' || (millis() - lastLineDetectedTime > 1800 && lastLineDetectedTime > 0)) {
      if (millis() - lastTurnTime < 1000) {
        if (debug) Serial.println("Ignoring repeated 'B' command due to cooldown.");
        return;
      }
      if (debug) Serial.println("Received 'BLACK' command. Turning 90°...");
      current_angle_gyro += turn_direction * 90;
      turn_count++;
      lastTurnTime         = millis();
      lastLineDetectedTime = 0;
      return;
    }
  }

  // “RED” or “GREEN” close to a cube and need to avoid it ➜ AVOID_CUBE
  if ((c == 'R' || c == 'G') && millis() - last_cube_time >= AVOIDANCE_DRIVE_TIME) {
    cube_avoid_direction = (c == 'R') ? 'L' : 'R';  // 'R' means turn left, 'G' turn right
    currentState         = AVOID_CUBE;
    last_cube_time       = millis();
    if (debug) {
      Serial.print("AVOID_CUBE dir ➜ ");
      Serial.println(cube_avoid_direction);
    }
    return;
  }

  if (debugcam) {
    Serial.print("Ignored cmd ➜ ");
    Serial.println(cmd);
  }
}
```

**“S…” (e.g. `"S+0.120\n"`):**
- Parses the float after `S`, sets `follow_cube_angle` to the value that was sent after S character, and switches to **FOLLOW_CUBE**.
- Records the time to `last_follow_cube` so we know how long it has been since the camera last issued a “follow” command.

**“BLACK”:**
- Only when in **PID**, add or substract 90° based on the lap direction, by adjusting `current_angle_gyro += ±90`.
- Increment `turn_count` and enforce a 1 s cooldown to avoid repeated turning signals.

**“RED” or “GREEN”:**
- When getting to close to a cube, it sets `cube_avoid_direction` based on the cube color and enter **AVOID_CUBE**.

#### Cube Avoidance Subroutine (pass_cube())
When in **AVOID_CUBE**, the robot executes a hardcoded movement, that includes a fixed turn + move forward maneuver to avoid the cube, then transitions to **AFTER_CUBE**, that alligns the robot for doing **PID** and follow the next cube.

```cpp
void pass_cube(char cube_direction) {
  read_gyro_data();
  // Convert 'R' ➜ +1 (turn left), 'G' ➜ -1 (turn right)
  int sign = (cube_direction == 'R') ? 1 : -1;

  double start_angle  = gz;
  double target_angle = start_angle - sign * AVOIDANCE_ANGLE;

  // Turn ~37° away from cube
  move_until_angle(robot_speed, target_angle);

  // Drive ~8 cm forward while holding that heading
  move_cm_gyro(8, robot_speed, target_angle);

  // Move to AFTER_CUBE case
  last_cube_time = millis();
  currentState   = AFTER_CUBE;

  // Discard any leftover UART messages before returning to PID
  flush_messages();
}
```

### Camera Side (OpenMV RT1062)
In the OpenMV python script, we detect the largest visible red or green blob in the bottom 40% section of the frame, while computing a PD steering error, and send either a small follow command "S±pid_error\n" or an avoid trigger "RED\n"/"GREEN\n" over UART.

**Choose Closest Cube & Follows it by using a PD algorithm**

```python
# ---- Choose Closest Cube (largest red or green) ----
candidates = []
if red_cube:   candidates.append(('R', red_cube))
if green_cube: candidates.append(('G', green_cube))

if candidates:
    # Pick the cube (red or green) with the largest area
    color_char, cube = max(candidates, key=lambda x: x[1].area())
    area = cube.area()
    col  = (255,0,0) if color_char == 'R' else (0,255,0)

    # Draw rectangle and crosshair on the selected cube
    img.draw_rectangle(cube.rect(), color=col)
    img.draw_cross(cube.cx(), cube.cy(), color=col)
    img.draw_string(cube.x(), cube.y() + cube.h() - 10,
                    str(area), color=col)

    # Compute normalized horizontal error in [-1, 1]
    error = (cube.cx() - target_x) / float(target_x)
    pid_error = kp_cube * error + kd_cube * (error - pid_last_error)
    pid_last_error = error

    if area < follow_threshold:
        # Send “S±error\n” to indicate a small servo correction (➜ FOLLOW_CUBE)
        uart.write("S{:+.3f}\n".format(error))
        if DEBUG:
            print("{} FOLLOW ➜ err:{:+.3f}, pid:{:+.3f}, area:{}".format(
                  "RED" if color_char == 'R' else "GREEN",
                  error, pid_error, area))
    else:
        # At close range, send just “RED\n” or “GREEN\n” to trigger avoidance
        uart.write(("RED\n" if color_char == 'R' else "GREEN\n"))
        if DEBUG:
            print("{} CLOSE ➜ area {} >= {}".format(
                  "RED" if color_char == 'R' else "GREEN",
                  area, follow_threshold))
```

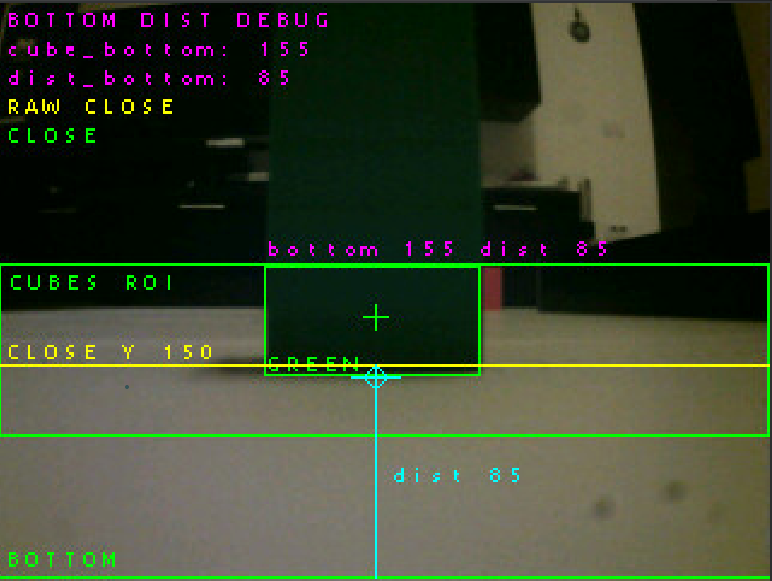
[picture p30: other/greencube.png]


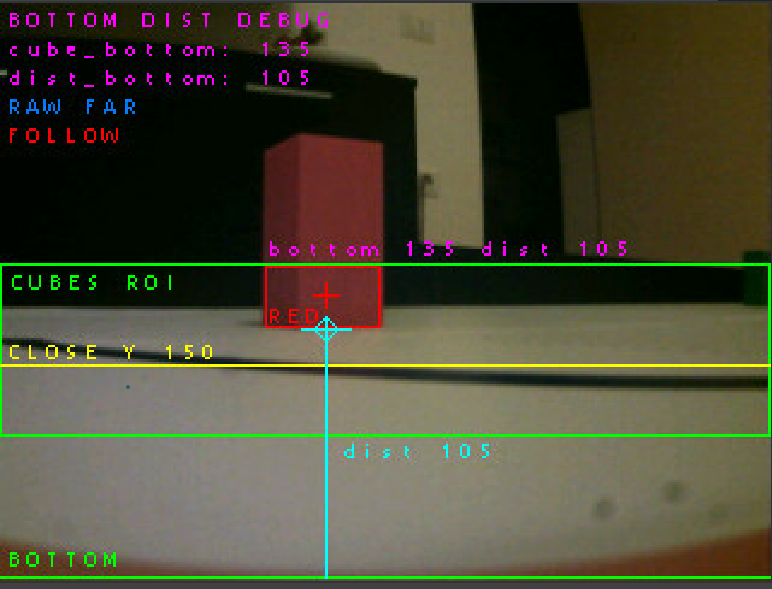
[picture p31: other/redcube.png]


### 🅿️ Starting from Parking 
At the start of the round, our robot is placed in the designated parking zone (the parking zone is 1.5x robot lenght). To determine the direction of the first lap (clockwise or counterclockwise), we use the 2 distance sensors placed on left and right side of our robot, the one that sees the wall further away will be the side to exit and do the laps.

Once the direction is determined, the robot performs an initial steering exit maneuver (to left or right) using our custom PD-based turning function:

```cpp
// Start from parking
if (RUN_MODE == 1) {
  if (readDistanceMM(LEFT_DIR, 3) < readDistanceMM(RIGHT_DIR, 3)) {  // exit right
    move_until_angle_max(exit_speed, 75);

    move(65);
    delay(100);

    turn_direction = 1;
    move_until_angle_max(exit_speed, 0);

    move_straight_on_gyro(-robot_speed, 900); // allign the robot to be able to pass cubes
  } else {  // exit left
    move_until_angle_max(exit_speed, -70);

    move(65);
    delay(100);

    turn_direction = -1;
    move_until_angle_max(exit_speed, 0);

    move_straight_on_gyro(-robot_speed, 1800); // allign the robot to be able to pass cubes
  }
}
```

The robot turns ~75° toward the main track depending on the detected direction. Following this parking exit, the robot enters its standard operating state:
- If it detects a cube, it enters **FOLLOW_CUBE** mode, where it tries to center itself on the cube using a PD algorithm.
- If the cube gets **too** close, it enters **AVOID_CUBE** mode, passing the cube left or right based on its color.
- After **AVOID_CUBE**, it automatically enters **AFTER_CUBE**, where it centers itself on the center of the track to prepare for searching the next cube.
- When no cube is detected, it enters **PID** mode, in which it simply navigates straight using the gyro—just as in qualification runs.

### 🅿️ Parking 

At the end of the run, once the robot has completed **12 turns in RUN\_MODE 1** (final run mode), it transitions into the **parallel parking sequence**. This routine is fully deterministic and relies on both **front and back distance sensors** together with the **gyro angle** to achieve a repeatable and precise result. The sequence consists of four main phases:

**1. Front-Wall Alignment**

The robot first drives forward until it reaches a **target offset from the front wall**, ensuring a consistent starting position for the parking maneuver.

* **Left course:** 470 mm from the front wall
* **Right course:** 460 mm from the front wall

This distance lock guarantees that the robot always starts the parking procedure at the same longitudinal reference point.

**2. Lane Reorientation**

Next, the robot performs a **90° snap turn** into the parking lane:

* **Heading update:** `current_angle_gyro += turn_direction * 90`
* **Correction:** On left courses, an additional `-3°` trim is applied for drift compensation.

This ensures the chassis is now parallel to the parking lane wall.

**3. Lane Squaring & Staging**

The robot then stabilizes its position inside the lane using a two-step process:

* Moves forward **200 mm** while holding the new heading (gyro-straight).
* Aligns on the **rear wall** by driving backwards until the back sensor reads **300 mm**.

Finally, it advances to a **staging distance** inside the lane, preparing for the parking maneuver:

* **Left course:** 900 mm from the front wall
* **Right course:** 1590 mm from the front wall

This places the robot in the correct position to start the 3-move parallel park.

**4. Three-Maneuver Parallel Parking**

The actual parallel parking is executed as three steering sweeps:

* **Left Course (`turn_direction = -1`)**

  1. **Reverse Arc:** Turn at `-75°` relative to prking spot.
  2. **Straighten Backwards:** Reduce angle to `-5°`.
  3. **Forward Tuck:** Correct forward sweep to `+5°`.

* **Right Course (`turn_direction = +1`)**

  1. **Reverse Arc:** Turn at `+75°` relative to parking spot.
  2. **Straighten Backwards:** Reduce angle to `+5°`.
  3. **Forward Tuck:** Correct forward sweep to `-2°`.

This sequence positions the robot in the parking zone, parallel to the wall and within the designated area.

**5. Final Stop**

Once the three-step maneuver is complete, the robot:

* Centers the steering servo.
* Cuts motor power (`move(0)`).
* Enters a **20-second idle state**, ending the run.

Code (for both lap directions):

```cpp
...
if (turn_count == 12 && RUN_MODE == 1) {
  move_straight_on_gyro(robot_speed, 500);
  if (turn_direction == -1) {
    move_to_distance(FRONT_DIR, 470.0f, 10.0f, 55, current_angle_gyro);
    current_angle_gyro += turn_direction * 90;
    current_angle_gyro -= 3;

    move_until_angle_max(60, current_angle_gyro);
    move_straight_on_gyro(robot_speed, 200);
    move_to_distance(BACK_DIR, 300.0f, 10.0f, -55, current_angle_gyro);
    move_to_distance(FRONT_DIR, 900.0f, 10.0f, 55, current_angle_gyro);

    // sensu de stanga
    move_until_angle_max(-60, (current_angle_gyro) - 75);
    move_until_angle_max(-60, (current_angle_gyro) - 5);
    move_until_angle_max(60, (current_angle_gyro) + 5);
  } else {
    move_to_distance(FRONT_DIR, 460.0f, 10.0f, 55, current_angle_gyro);
    current_angle_gyro += turn_direction * 90;

    move_until_angle_max(60, current_angle_gyro);
    move_straight_on_gyro(robot_speed, 200);
    move_to_distance(BACK_DIR, 300.0f, 10.0f, -55, current_angle_gyro);
    move_to_distance(FRONT_DIR, 1590.0f, 10.0f, 55, current_angle_gyro);

    move_until_angle_max(-63, (current_angle_gyro)+75);
    move_until_angle_max(-63, (current_angle_gyro)+5);
    move_until_angle_max(60, (current_angle_gyro)-2);
  }

  steeringServo.write(STEERING_CENTER);
  delay(300);

  move(0);
  delay(20000);
}
...
```

Parking Sequence flowchart:
```txt
Detect Parking Area
      ↓
Align To Front Wall
      ↓
Reverse With Steering
      ↓
Align Parallel
      ↓
Stop Inside Parking
```

---

### ⚠️ Edge Cases and Failure Handling 

During testing, several failure cases were identified and handled in software. These protections make the robot more reliable because the program does not depend on every sensor reading being perfect.

| Failure Case | Possible Cause | Software Response |
|---|---|---|
| Cube temporarily lost from camera view | Motion blur, lighting, cube outside ROI | Return from FOLLOW_CUBE to PID after timeout |
| Repeated black line detection | Camera sees the same turn marker multiple times | Cooldown timer prevents repeated 90° turns |
| Wrong color detection | Reflections or lighting variation | LAB threshold tuning and ROI filtering |
| Robot drifts after avoidance | Uneven floor, steering error, gyro drift | AFTER_CUBE state re-aligns heading before normal PID |
| Parking zone not detected immediately | Camera angle, sensors angle or object position | Continue searching after completing required laps |
| Sudden voltage drop | Impeller or servo current spike | Impeller ramp-up and separated power strategy |

---

## 📽️ Performance Video 

🔗 **[Click here to watch the video on YouTube](https://www.youtube.com/watch?v=bg92ulHXomw)** 

---

## 💰 Cost Analysis 

We optimized the robot for a balance between **high performance, reliability, and cost efficiency**. The total cost includes electronics, motors, sensors, PCB manufacturing, 3D printed parts, and mechanical hardware used during both development and the final competition-ready version.

### 📦 **Components Costs** 

**Note:** Many of the components used in this project were provided through sponsorships and partnerships. The prices listed above represent the standard market prices without sponsor discounts, in order to reflect the real estimated value of the robot.
> 
| Component | Quantity | Unit Price ($) | Total ($) |
|---|---|---|---|
| Arduino Nano ESP32 | 1 | 21.42 | 21.42 |
| Drive Motor 6V (30:1 HPCB) | 1 | 22.45 | 22.45 |
| IFX9201SG Motor Driver | 1 | 4.62 | 4.62 |
| Steering Servo (MG90S) | 1 | 4.05 | 4.05 |
| OpenMV RT1062 Camera | 1 | 80.00 | 140.00 |
| Gyroscope (BMI088) | 1 | 8.50 | 8.50 |
| Pololu Distance Sensor | 4 | 17.95 | 71.80 |
| LiPo Battery (2S 300mAh) | 1 | 5.60 | 5.60 |
| D24V50F5 Voltage Regulator | 1 | 29.95 | 29.95 |
| Custom Silicone Wheels | 4 | 9.24 | 36.96 |
| RC Differential | 1 | 19.00 | 19.00 |
| Experimental Parts | - | 35.00 | 35.00 |
| **TOTAL COMPONENT COST** | - | **-** | **363.35** |

### 🧪 Experimental Parts & Development Iterations

During development, multiple experimental parts and prototype versions were tested before reaching the final design. These included:
- Different wheel compounds and tire designs
- Alternative PCB revisions
- Various motor ratios and steering geometries
- Prototype chassis parts and sensor mounts

These parts were mainly used for testing and optimization and are not included in the final competition robot cost.

---

### **🔌 PCB Cost (Manufactured via JLCPCB)** 
| PCB Component | Board | Quantity | Unit Price ($) | Total ($) |
|---|---|---|---|---|
| **PCB Manufacturing (JLCPCB)** | Main | 5 | **1.3** | **6.5** |
| | IMU | 5 |  **6.644** | **33.22** |
| **PCB Assembly (JLCPCB)** | Main | 5 | **0.82** | **4.10** |
| | IMU | 5 | **21.826** | **109.13** |
| **TOTAL PCB COST** | ALL | 5*2=10 | **30.59** | **152.95** |

---

### **🖨️ 3D Printing Cost Breakdown** 

For 3D Printing we used Anycubic Kobra S1 Printer, and as well for some high quality resing printing we used the 3DP service from JLC.

| 3D Printed Parts | Quantity | Unit Price ($) | Total ($) |
|---|---|---|---|
| **1000g Anycubic PLA+ filament** | 1 | **16.99** | **16.99** |
| **1000g Anycubic ABS filament** | 1 | **21.99** | **21.99** |
| **TOTAL 3D PRINTING COST** | | | **38.98** |

---

### **🔩 Other Materials (Screws, Nuts, and Miscellaneous)** 
| Material | Quantity | Unit Price ($) | Total ($) |
|---|---|---|---|
| **M2/M3 Screws & Nuts** | - | **-** | **10.00** |
| **Wiring & Connectors** | - | **-** | **10.00** |
| **TOTAL OTHER MATERIALS COST** | | | **20.00** |

---

### **💵 TOTAL** 
| Category | Total Cost ($) |
|---|---|
| **Components** | **363.35** |
| **PCB (JLCPCB + Components)** | **30.59** |
| **3D Printing** | **38.98** |
| **Other Materials** | **20.00** |
| **TOTAL PROJECT COST** | **452.92** |

**Prices are approximate, based on current market prices.*

---

## 🔁 Reproducibility Guide 

Another team or person should be able to rebuild the robot by following the files and documentation in this repository.

### 1. Mechanical Build
1. Print the parts from the `3D-models` folder.
2. Use the technical drawings from `technical-draws` to check dimensions and orientation.
3. Assemble the rear drivetrain, differential, motor mount, and wheel hubs.
4. Mount the steering servo and front steering hubs.
5. Install the silicone tires on the wheels.
6. Mount the impeller and make sure the airflow path is not blocked.

### 2. Electronics Assembly
1. Use the wiring files from `electrical-schematics`.
2. Connect the Arduino Nano ESP32, OpenMV camera, motor driver, servo, IMU, distance sensors, and voltage regulator.
3. Check power polarity before connecting the Li-Po battery.
4. Test the regulated voltage before connecting sensitive components.
5. Confirm UART communication between the OpenMV camera and Arduino.

### 3. Software Upload
1. Upload the Arduino code from the `src` folder to the Arduino Nano ESP32.
2. Upload the OpenMV Python script to the OpenMV RT1062 camera.
3. Open serial debug during first tests to verify sensor messages.
4. Calibrate camera thresholds for the current lighting.
5. Reset IMU heading before the first autonomous run.

### 4. First Test Run
1. Test steering center without driving.
2. Test drive motor direction and braking.
3. Test camera detection for orange, blue, red, green, black, and magenta.
4. Test gyro-based 90° turns.
5. Test cube following and avoidance at low speed.
6. Test parking only after lane following and obstacle logic are stable.

---

## 🎲 Randomizer 

To make testing more realistic and closer to the official WRO Future Engineers format, we built our own custom **WRO Future Engineers Randomizer**.

🔗 **Available here:** [https://wro-fe-randomizer.hyperlinerobotics.com/](https://wro-fe-randomizer.hyperlinerobotics.com/)

The randomizer helps us quickly generate valid challenge layouts for both practice and robot testing. Instead of manually choosing cube positions, parking walls, starting positions, and field elements, the tool automatically creates randomized configurations based on the competition rules.

This is useful during development because the robot must be able to adapt to many possible field layouts, not only one fixed setup. By using the randomizer, we can test different cases repeatedly and improve the reliability of our algorithms for:

* Open Challenge starting positions
* Final Round cube placement
* Repeated full-run practice under randomized conditions

The randomizer became an important part of our testing workflow because it allows us to train and debug the robot in conditions that are much closer to the real competition environment.

---

## 📂 Resources 

Below is a compact list of **external images** used in this repository.

| Category | Resources |
|---|---|
| Social Badges | [Website](https://img.shields.io/badge/Website-000?style=for-the-badge&logo=google-chrome&logoColor=white), [YouTube](https://img.shields.io/badge/YouTube-FF0000?style=for-the-badge&logo=youtube&logoColor=white), [Instagram](https://img.shields.io/badge/Instagram-E4405F?style=for-the-badge&logo=instagram&logoColor=white), [X](https://img.shields.io/badge/X-000000?style=for-the-badge&logo=x&logoColor=white), [Facebook](https://img.shields.io/badge/Facebook-1877F2?style=for-the-badge&logo=facebook&logoColor=white), [GitHub](https://img.shields.io/badge/GitHub-181717?style=for-the-badge&logo=github&logoColor=white), [OSHWLab](https://img.shields.io/badge/OSHWLab-0A7DFF?style=for-the-badge&logo=opensourcehardware&logoColor=white) |
| Sponsor Logos | [OpenMV](https://hyperlinerobotics.com/assets/images/sponsors/openmv.avif), [EasyEDA](https://hyperlinerobotics.com/assets/images/sponsors/EasyEDA_logo.png), [OSHWLab](https://hyperlinerobotics.com/assets/images/sponsors/OSHWLab.png), [LCSC](https://static.lcsc.com/feassets/pc/images/headIcons/logo-s.png), [ING](https://hyperlinerobotics.com/assets/images/sponsors/ING.png), [Fundația Comunitară București](https://hyperlinerobotics.com/assets/images/sponsors/FundatiaComunitaraBucuresti.png), [SoBotz](https://hyperlinerobotics.com/assets/images/sponsors/SoBotz-white.png), [JSumo](https://jsumo.com/Data/EditorFiles/jsumo-robot-parts-logo.png), [Evergreen](https://hyperlinerobotics.com/assets/images/sponsors/evergreen.png), [FAE Drones](https://fae-drones.com/wp-content/uploads/2022/08/logo-vertical-ro.png) |
| Robot Parts | [Pololu Gearmotor](https://a.pololu-files.com/picture/0J12418.220.jpg?8f026fe1675b1109ea574290d3d26081), [IFX9201SG Driver](https://assets.lcsc.com/images/lcsc/900x900/20230316_Infineon-Technologies-IFX9201SG_C112633_front.jpg), [MG90S Servo](https://static.optimusdigital.ro/20565-large_default/mg90s-servomotor.jpg), [Li-Po Battery](https://img-va.myshopline.com/image/store/2000408386/1640672930478/GNB3002S60AHV-(4)_1800x.jpeg?w=1000&h=1000), [Arduino Nano ESP32](https://store.arduino.cc/cdn/shop/files/ABX00092_01.iso_804x603.jpg?v=1727101612), [OpenMV RT1062](https://openmv.io/cdn/shop/files/cam-v5-front-hero-2-web_1000x.jpg?v=1699323324), [Pololu Distance Sensor](https://a.pololu-files.com/picture/0J11135.1200.jpg?1910ced553e34153046a4c95021a93b3), [Voltage Regulator](https://gomagcdn.ro/domains/robofun.ro/files/product/large/pololu-5v-5a-step-down-voltage-regulator-d24v50f5-633511-832-442353.jpg) |

**Note:** All external images are credited to their original owners and are used only for documentation and component reference purposes.

---

## 📜 License 
```
MIT License

Copyright (c) 2026 Popescu Filimon Andrei Cosmin

Permission is hereby granted, free of charge, to any person obtaining a copy
of this software and associated documentation files (the "Software"), to use,
copy, modify, merge, publish, distribute, sublicense, and/or sell copies of
the Software, subject to the following conditions:

The above copyright notice and this permission notice shall be included in all
copies or substantial portions of the Software.

Competition Fair Use Notice

This project was created for the 2026 WRO Future Engineers competition season.

You may use this repository for learning, testing, studying, and educational
experimentation. However, you are not allowed to copy, submit, or use this work
as your own competition solution during the same competition year for which it
was created, namely 2026.

Using this project to directly compete against the original team in the same
competition season, without major original modifications and without proper
credit, is considered unfair use and goes against the spirit of open-source
sharing, fair play, and engineering ethics.

THE SOFTWARE IS PROVIDED "AS IS", WITHOUT WARRANTY OF ANY KIND, EXPRESS OR
IMPLIED, INCLUDING BUT NOT LIMITED TO THE WARRANTIES OF MERCHANTABILITY,
FITNESS FOR A PARTICULAR PURPOSE AND NONINFRINGEMENT. IN NO EVENT SHALL THE
AUTHORS OR COPYRIGHT HOLDERS BE LIABLE FOR ANY CLAIM, DAMAGES OR OTHER
LIABILITY, WHETHER IN AN ACTION OF CONTRACT, TORT OR OTHERWISE, ARISING FROM,
OUT OF OR IN CONNECTION WITH THE SOFTWARE OR THE USE OR OTHER DEALINGS IN THE
SOFTWARE.
```

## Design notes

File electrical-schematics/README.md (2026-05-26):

# electrical-schematics - Electrical Schematics

This folder contains the circuit diagrams and wiring layouts for the robot's electronics. Also we added the 3 files needed for PCB production with assembly at JLCPCB.

`PCB Schematics.png` - PCB Schematics, containing all robot connections
`SCH_IMU.png` - IMU Schematics, containing all custom IMU components connections
`PCB Routing.png` - Shows PCB Routes

**Production Files:**
Main Chassis:
Gerber: `PCBGerber.zip`
BOM: `BOM_PCB.xlsx`
Pick And Place: `PickAndPlace_PCB.xlsx`

IMU:
Gerber: `PCB_IMU.zip`
BOM: `BOM_IMU.xlsx`
Pick And Place: `PickAndPlace_IMU.xlsx`

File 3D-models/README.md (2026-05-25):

# 3D-models - 3D Models

This folder contains 3D design files for the robot's components. These files include parts used in the vehicle's steering and drivebase. Formats include STL and/or STEP files.

### Models

- `front-wheel.stl`: Front wheel with integrated bearing support, designed for smooth steering and reduced wobbling during high-speed movement.
- `back-wheel.stl`: Rear drive wheel optimized for traction and compatibility with the custom differential system.
- `left-steering-hub.stl`: Left steering hub connecting the front wheel to the steering linkage while allowing low-friction rotation.
- `right-steering-hub.stl`: Right steering hub designed symmetrically to the left hub for stable and precise steering control.
- `motor-drive-gear.stl`: Gear mounted on the drive motor shaft, transferring power to the differential input gear.
- `motor-and-wheel-hub(main-drive-hub).stl`: Main rear drivetrain support holding the motor, differential, wheel axles, and bearings in a compact assembly.
- `impeller-base.stl`: Structural support used to mount the impeller motor and maintain stable airflow underneath the robot.
- `impeller-fan.stl`: Lightweight impeller fan designed to generate aerodynamic downforce for increased traction.
- `steering-bar.stl`: Steering linkage connecting both front steering hubs to the servo arm for synchronized wheel movement.
- `battery-support.stl`: Mounting structure securing the Li-Po battery while keeping the center of gravity low and centered.
- `steering-and-camera-mount-hub.stl`: Combined structural mount holding both the steering servo and OpenMV camera in fixed alignment.

### Archive
- `old-3D-models/`: Contains earlier versions of the robot's 3D models for reference.

## Usage
- Download the `.stl` or `.step`(if available) files to fabricate the components using a 3D printer or CNC machine.
- Ensure the parts are assembled according to the robot's full assembled design.

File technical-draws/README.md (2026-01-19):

# Technical Drawings

This folder contains detailed technical drawings for the robot's components. These drawings provide precise dimensions and specifications required for manufacturing and assembly.

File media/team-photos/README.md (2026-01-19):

# team-photos - Team Photos

This folder includes photos of the team members during various stages of the project.

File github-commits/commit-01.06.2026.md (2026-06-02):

Commit - 1/06/2026

* Added final media and robot performance/assembly video
* Uploaded final code

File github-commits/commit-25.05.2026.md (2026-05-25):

Commit - 25/05/2026

* Finishing writing the markdown
* Uploaded the final 3D Models
* Uploaded the final electrical schematics and PCB production files
* Uploaded robot media

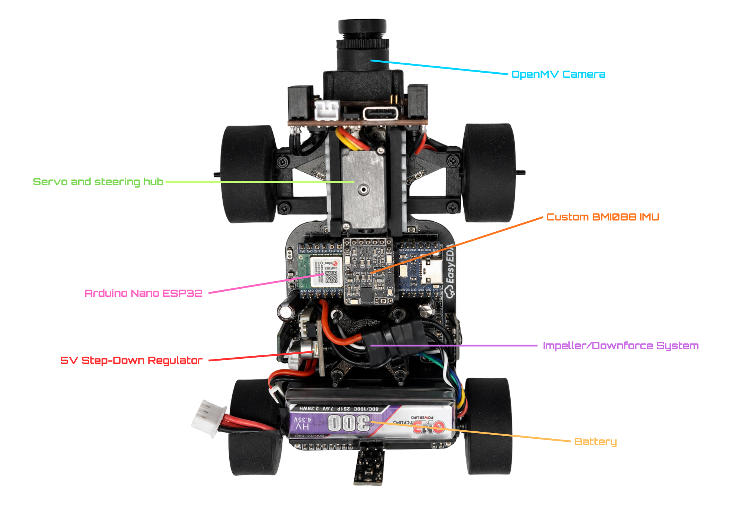
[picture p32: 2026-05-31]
other/Robot-Overview.png

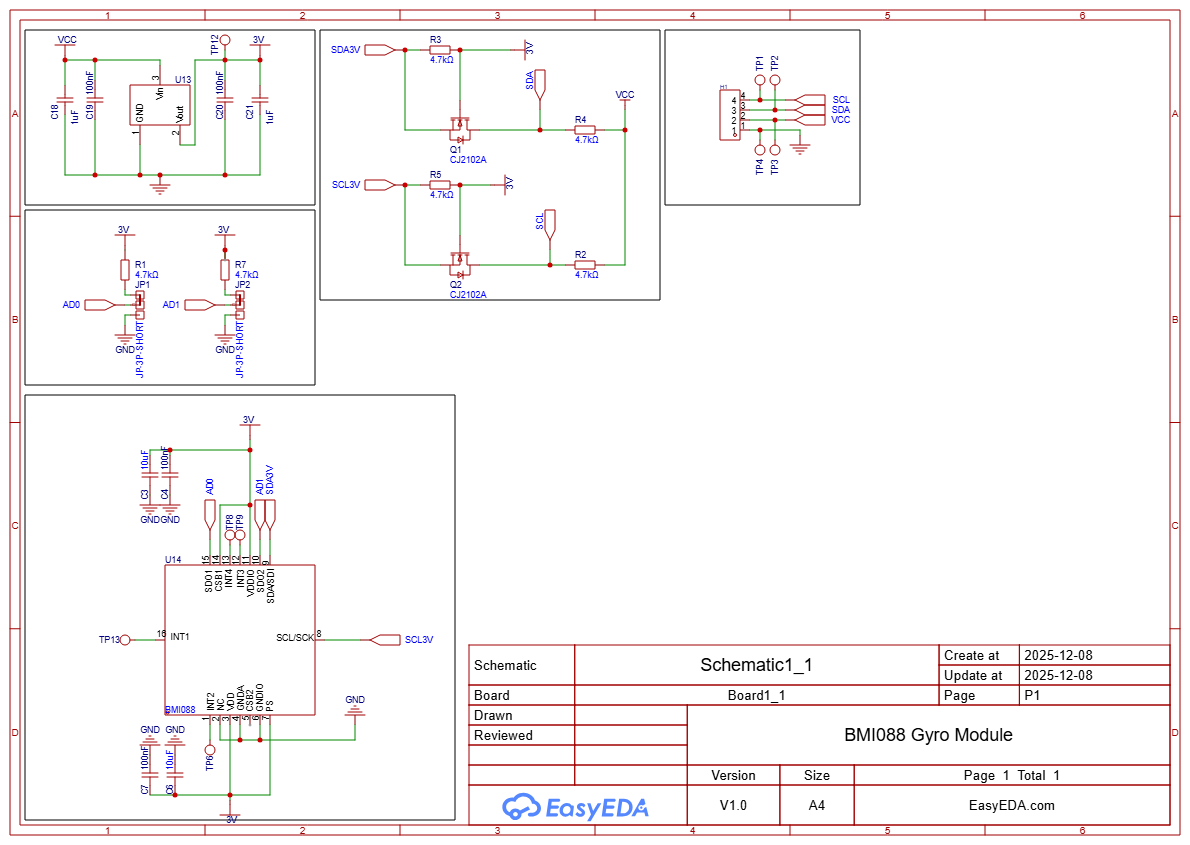
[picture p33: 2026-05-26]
electrical-schematics/SCH_IMU.png

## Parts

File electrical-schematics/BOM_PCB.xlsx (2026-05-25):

No. | Quantity | Comment | Designator | Footprint | Value | Manufacturer Part | Manufacturer | Supplier Part | Supplier
1 | 1 | HDR-F_2.54_1x5P | 5V 5A Regulator | HDR-TH_5P-P2.54-V-F
2 | 1 | KH-2.54PH180-1X2P-L11.5 | - + | HDR-TH_2P-P2.54-V-M |  | KH-2.54PH180-1X2P-L11.5 | kinghelm(金航标) | C2905434 | LCSC
3 | 2 | 220uF | C1,C2 | CAP-TH_BD6.3-P2.50-D1.0-FD | 220uF | KM221M025E110A | CapXon(丰宾) | C59416 | LCSC
4 | 1 | 100nF | C6 | C0805 | 100nF | 0805B104M250CT | Walsin(华新科) | C163183 | LCSC
5 | 2 | 2.54-1*2P母 | CameraData,CameraPower | HDR-TH_2P-P2.54-V-F |  | 2.54-1*2P母 | BOOMELE(博穆精密) | C49661 | LCSC
6 | 1 | DistFront | DistS1 | HDR-TH_3P-P2.54-V-F
7 | 1 | DistRight | DistS2 | HDR-TH_3P-P2.54-V-F
8 | 1 | DistBack | DistS3 | HDR-TH_3P-P2.54-V-F
9 | 1 | DistLeft | DistS4 | HDR-TH_3P-P2.54-V-F
10 | 1 | 2.54-1*6P母 | Encoder | HDR-TH_6P-P2.54-V-F |  | 2.54-1*6P母 | BOOMELE(博穆精密) | C40877 | LCSC
11 | 1 | 2.54-1*4P母 | Gyro | HDR-TH_4P-P2.54-V-F |  | 2.54-1*4P母 | BOOMELE(博穆精密) | C2718488 | LCSC
12 | 1 | IFX9201SGAUMA1_ | IFX_A1 | PG-DSO-12-17
13 | 4 | XL-1608UBC-04 | LED1,LED2,LED3,LED4 | LED0603-RD_RED |  | XL-1608UBC-04 | XINGLIGHT(成兴光) | C965807 | LCSC
14 | 1 | MST-12D18G4 SPDT Slide Switch | ON | SW-SMD_MST-12D18G4-SPDT-SLIDE-SWITCH |  | MST-12D18G4 SPDT Slide Switch | SHOU HAN(首韩) | C49023767 | LCSC
15 | 4 | 470Ω | R4,R5,R6,R7 | R0603 | 470Ω | 0603WAF4700T5E | UNI-ROYAL | C23179 | LCSC
16 | 2 | B3U-1000P | RST,START | KEY-SMD_B3U-1000PM |  | B3U-1000P | OMRON(欧姆龙) | C231329 | LCSC
17 | 1 | HDR-F_2.54_1x3P | Servo | HDR-TH_3P-P2.54-V-F
18 | 1 | ARDUINO_NANO | U4 | COMM-TH_ARDUINO_NANO |  | ARDUINO_NANO |  | C9900017879 | LCSC

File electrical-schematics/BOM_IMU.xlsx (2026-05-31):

No. | Quantity | Comment | Designator | Footprint | Value | Manufacturer Part | Manufacturer | Supplier Part | Supplier
1 | 2 | 10uF | C3,C6 | C0603 | 10uF | CL10A106KP8NNNC | SAMSUNG(三星) | C19702 | LCSC
2 | 4 | 100nF | C4,C7,C19,C20 | C0603 | 100nF | CC0603KRX7R9BB104 | YAGEO(国巨) | C14663 | LCSC
3 | 2 | 1uF | C18,C21 | C0603 | 1uF | CL10A105KB8NNNC | SAMSUNG(三星) | C15849 | LCSC
4 | 1 | 2.54-1*4P母 | H1 | HDR-TH_4P-P2.54-V-F |  | 2.54-1*4P母 | BOOMELE(博穆精密) | C2718488 | LCSC
5 | 2 | JP-3P-SHORT | JP1,JP2 | 3P-SMD-SHORT
6 | 2 | CJ2102A | Q1,Q2 | SOT-323-3_L2.0-W1.3-P1.30-LS2.3-BR |  | CJ2102A | CJ(江苏长电/长晶) | C19267744 | LCSC
7 | 6 | 4.7kΩ | R1,R2,R3,R4,R5,R7 | R0603 | 4.7kΩ | RC0603FR-074K7L | YAGEO(国巨) | C99782 | LCSC
8 | 5 | TEST-POINT'4545' | TP6,TP8,TP9,TP12,TP13 | TP-D45MIL
9 | 1 | XC6206P302MR-G | U13 | SOT-23-3_L2.9-W1.6-P1.90-LS2.8-BR |  | XC6206P302MR-G | TOREX(特瑞仕) | C9972 | LCSC
10 | 1 | BMI088 | U14 | LGA-16_L4.5-W3.0-P0.50-BL |  | BMI088 | Bosch(博世) | C194919 | LCSC

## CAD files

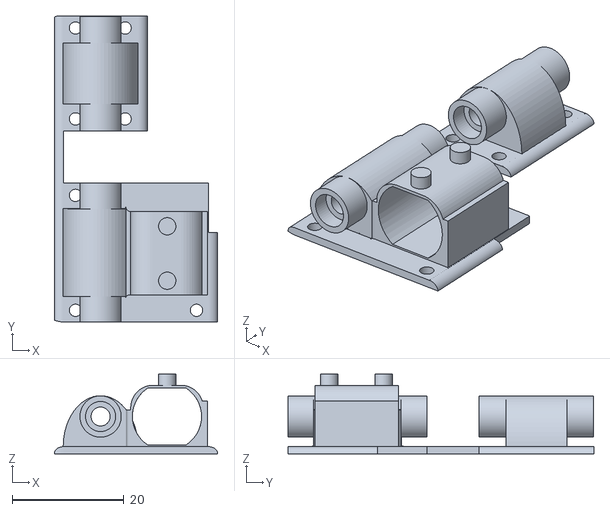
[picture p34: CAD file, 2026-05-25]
3D-models/motor-and-wheel-hub(main-drive-hub).stl
29.3 x 54.8 x 14.3

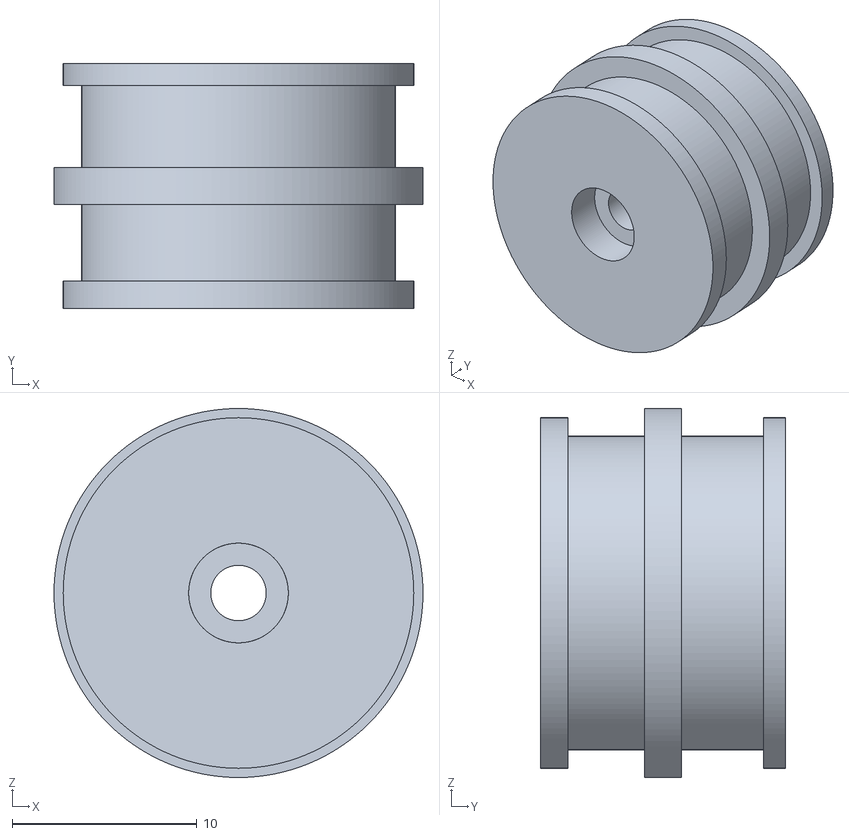
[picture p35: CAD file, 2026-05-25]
3D-models/back-wheel.stl
20.0 x 13.3 x 20.0

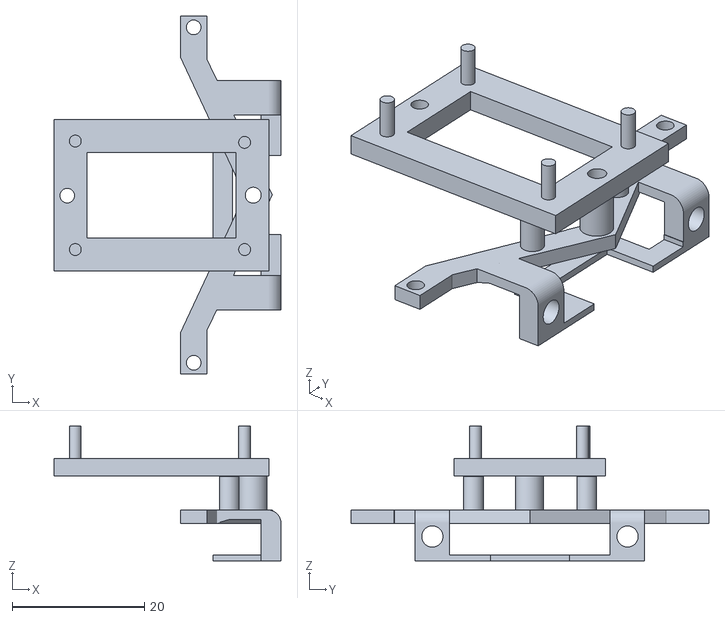
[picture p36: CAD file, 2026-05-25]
3D-models/steering-and-camera-mount-hub.stl
34.3 x 54.1 x 20.4

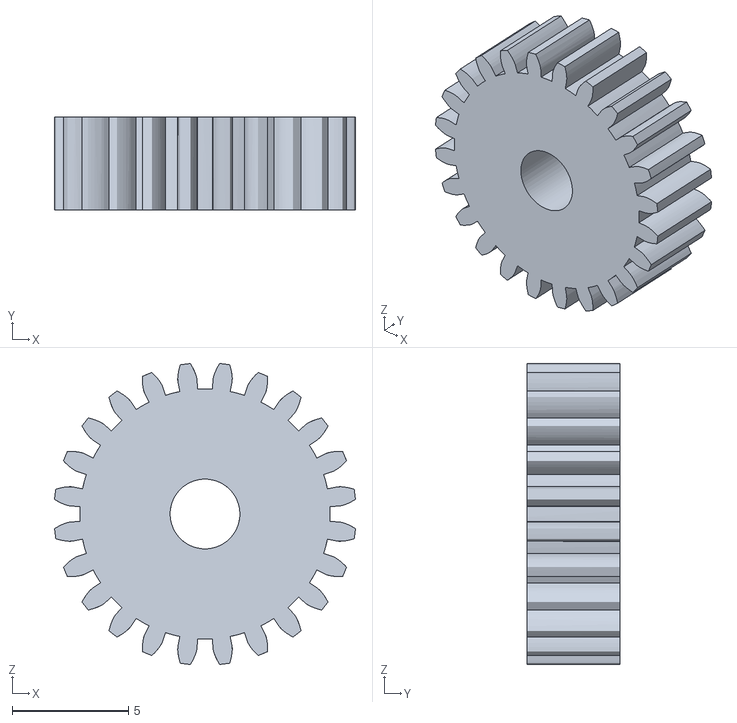
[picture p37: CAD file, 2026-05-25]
3D-models/motor-drive-gear.stl
12.9 x 4.00 x 12.9

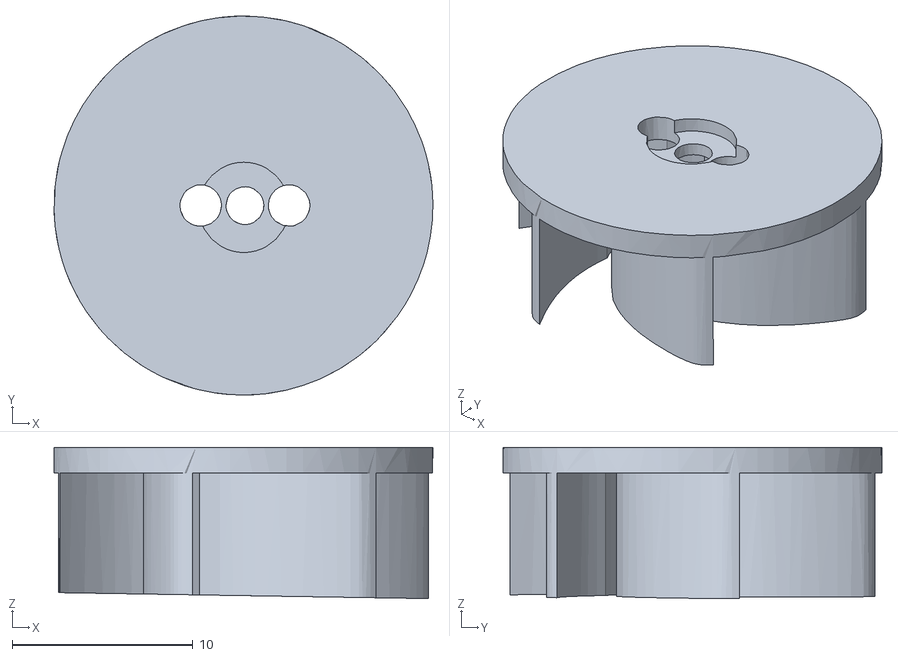
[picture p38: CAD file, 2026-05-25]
3D-models/impeller-fan.stl
21.0 x 21.0 x 8.38

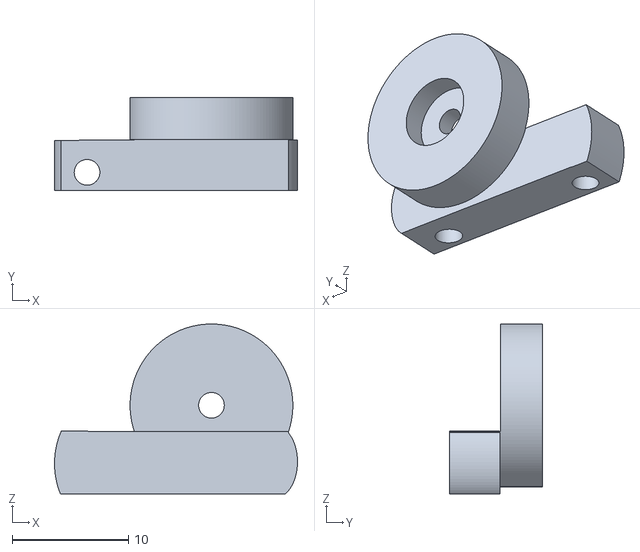
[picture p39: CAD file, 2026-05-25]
3D-models/left-steering-hub.stl
20.9 x 7.99 x 14.6

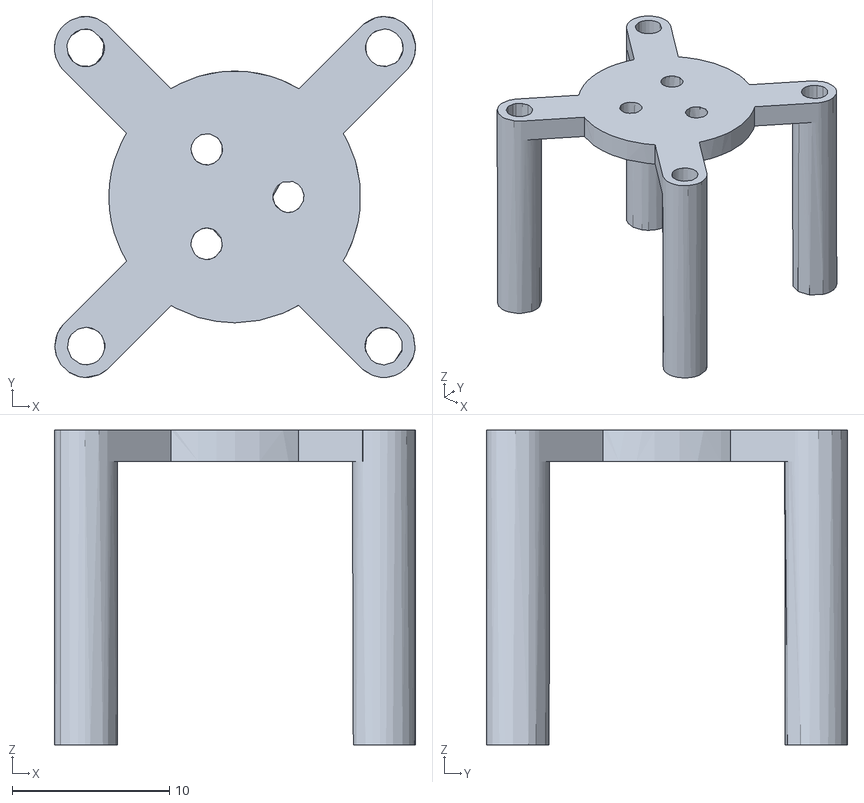
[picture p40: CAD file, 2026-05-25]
3D-models/impeller-base.stl
23.0 x 22.9 x 20.0

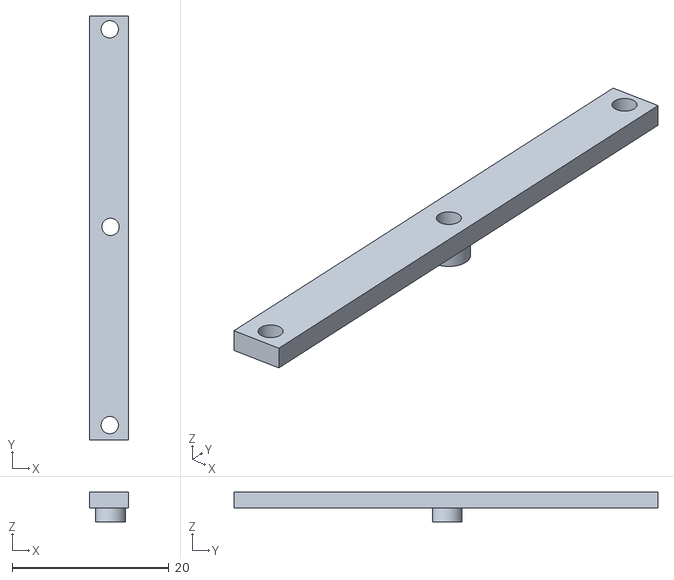
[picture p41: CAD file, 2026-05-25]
3D-models/steering-bar.stl
5.00 x 54.1 x 3.80

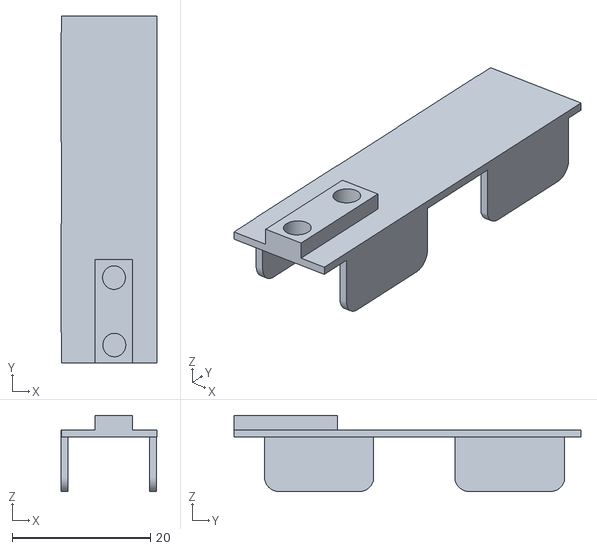
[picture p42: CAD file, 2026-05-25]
3D-models/battery-support.stl
13.9 x 50.2 x 11.0

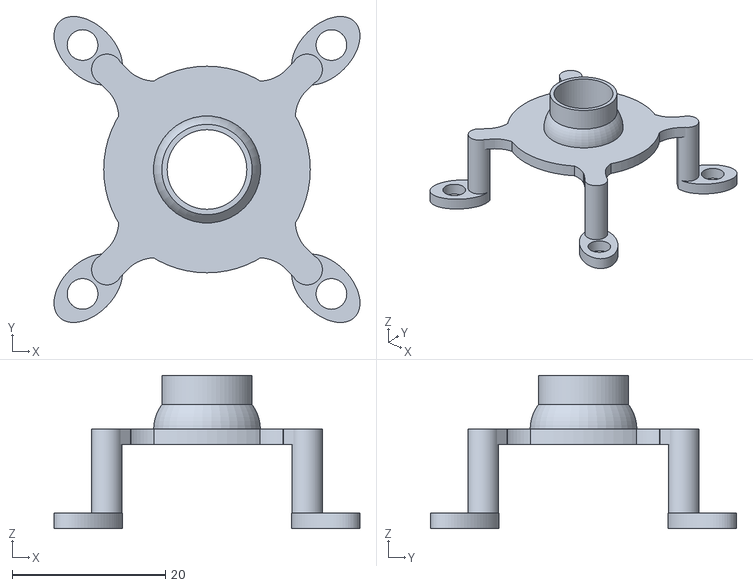
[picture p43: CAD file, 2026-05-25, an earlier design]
3D-models/old-3D-models/impeller-base.stl
40.0 x 40.0 x 20.0

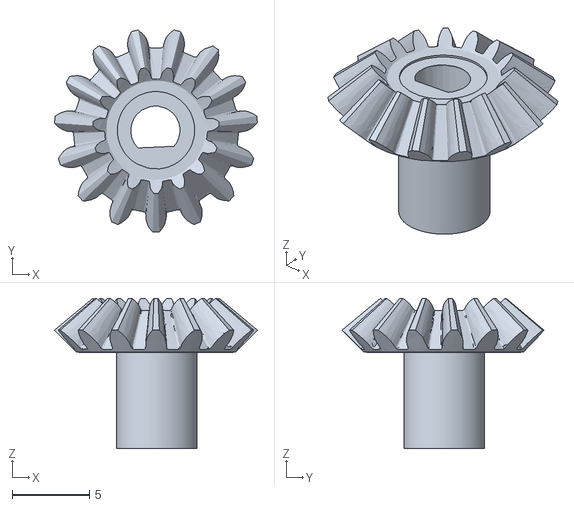
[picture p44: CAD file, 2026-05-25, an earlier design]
3D-models/old-3D-models/pinion-differential.stl
13.1 x 13.0 x 9.70

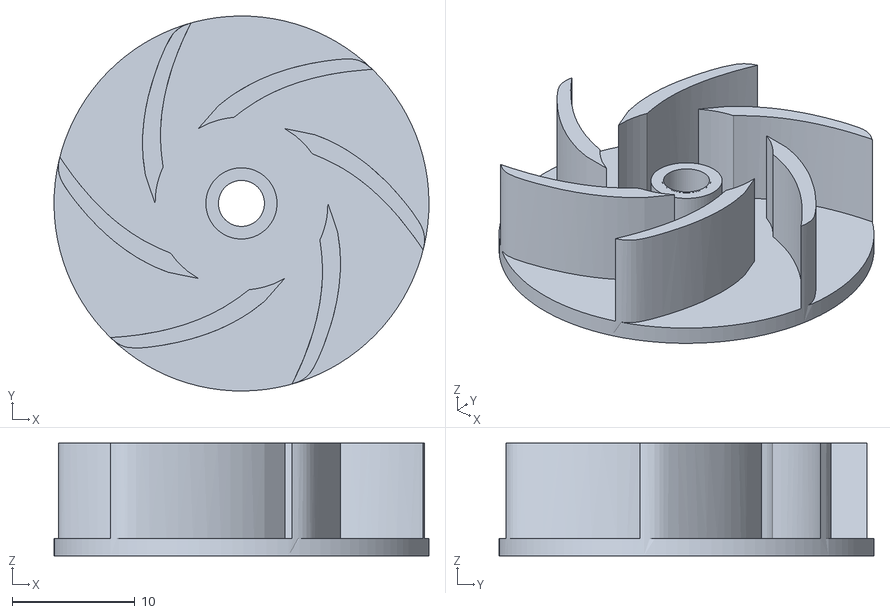
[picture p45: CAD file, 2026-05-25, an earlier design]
3D-models/old-3D-models/impeller-fan.stl
30.6 x 30.6 x 9.20

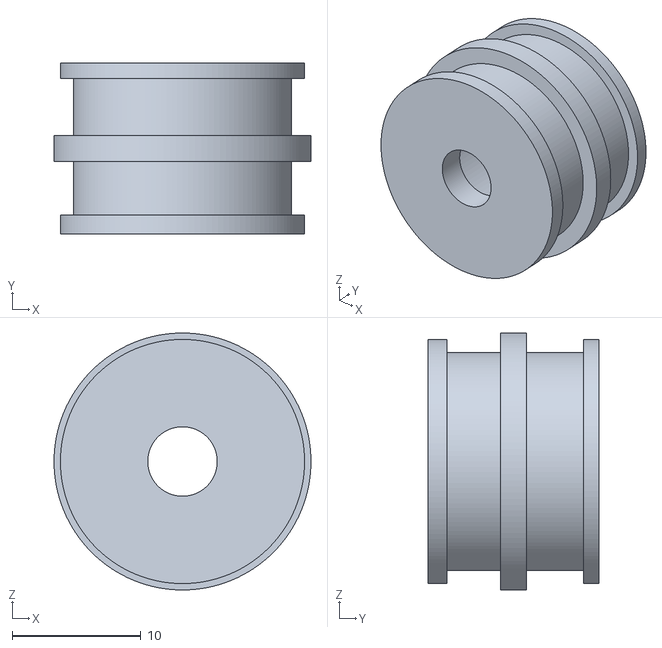
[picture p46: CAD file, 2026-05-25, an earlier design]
3D-models/old-3D-models/front-wheel.stl
20.0 x 13.3 x 20.0

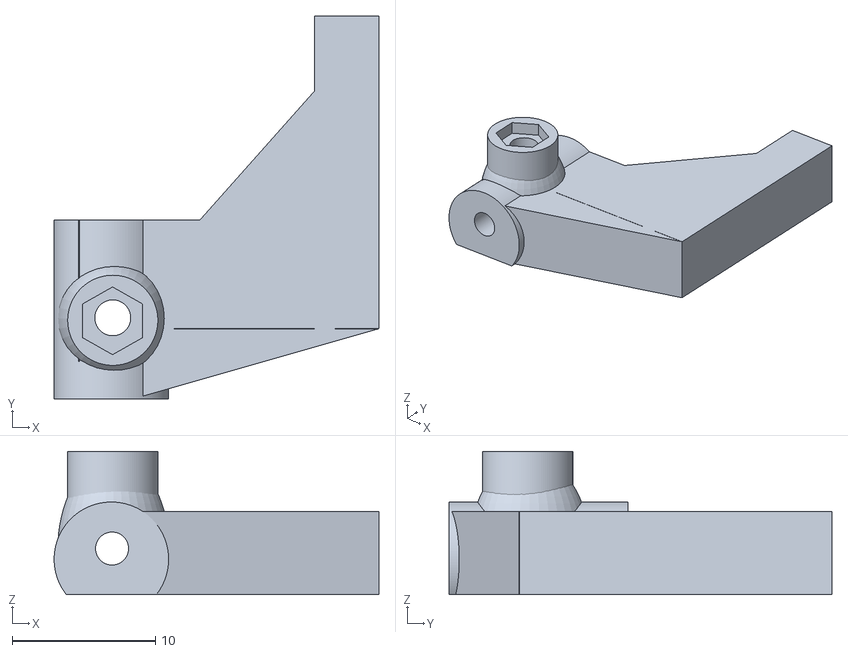
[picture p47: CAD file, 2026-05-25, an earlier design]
3D-models/old-3D-models/steering-left-hub.stl
22.7 x 26.8 x 10.0

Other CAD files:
3D-models/right-steering-hub.stl
3D-models/front-wheel.stl
3D-models/old-3D-models/back-rings-for-differential-to-wheel-axles.stl
3D-models/old-3D-models/back-wheel.stl
3D-models/old-3D-models/drive-motor-support-with-battery.stl
3D-models/old-3D-models/openmv-camera-mounts.stl
3D-models/old-3D-models/servo-to-wheel-hub-fixed-bar.stl
3D-models/old-3D-models/steering-right-hub.stl
3D-models/old-3D-models/steering-servo-to-hub-bar.stl

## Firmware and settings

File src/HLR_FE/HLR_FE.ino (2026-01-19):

// ================================================================
//               H Y P E R L I N E   R O B O T I C S
// ================================================================
//                    FIRMWARE:  HLR_FE.1  (Debug Edition)
//                    ROBOT UNIT:  #1
//                    PLATFORM:    Arduino Nano ESP32, OpenMV, IFX9201SG
//                    DEVELOPED BY: Popescu Filimon Andrei Cosmin, Eduar Alexandru Vasile
// ================================================================
#include <Wire.h>
#include <math.h>
#include <ESP32Encoder.h>
#include <ESP32Servo.h>
#include <SoftwareSerial.h>
#include "BMI088.h"

#define RUN_MODE 1  // 0 - Open Round, 1 - Cubes Round

// ================ Pin Definitions ================
#define PWMA D7
#define DIRA D8

#define PWM_IMPELLER D9

#define START_BTN D10

#define P4 D0
#define P5 D1

#define DEBUG_LED1 D6
#define DEBUG_LED2 D3

#define PWM_DIST_FRONT A0
#define PWM_DIST_BACK A2
#define PWM_DIST_LEFT A3
#define PWM_DIST_RIGHT A1

// ======= Distance sensor direction enum =======
enum DistanceDir : uint8_t { FRONT_DIR,
                             LEFT_DIR,
                             RIGHT_DIR,
                             BACK_DIR };


// ================ Speed Control ================
int robot_speed = 56;  // 57 - 59 // 100
int exit_speed = 56;
int park_speed = 58;
int impeller_speed = 0;
int cube_last = 1;

// === Encoder pins ===
#define ENCODER_A D5
#define ENCODER_B D4
volatile int32_t encoder_ticks = 0;

#define PPR 12.0f  // 12 pulses per rev, single-edge
#define QUAD_EDGES (PPR * 4.0f)
#define GEAR_RATIO 1.0f
#define WHEEL_DIAM 29.0f  // mm
#define MM_PER_TICK 1.18f

// ================ Motors and PID ================3
double current_angle_gyro = 0.0;  // steering asymmetry
double kp = 0.038;                // 0.044
double ki = 0;
double kd = 0.061;  // 0.082
double pid_error = 0, pid_last_error = 0;

// Integration & drift
double gyro_last_read_time = 0; 
double drifts_z = 0;  // drift in °/s
double gz = 0;        // integrated angle in degrees


#define PWM_MOTOR_CHANNEL 5
#define PWM_MOTOR_FREQ 1000
#define PWM_MOTOR_RESOLUTION 8

#define PWM_IMPELLER_CHANNEL 4
#define PWM_IMPELLER_FREQ 1000
#define PWM_IMPELLER_RESOLUTION 8


#define STEERING_SERVO D2
Servo steeringServo;
#define STEERING_LEFT 135
#define STEERING_CENTER 85
#define STEERING_RIGHT 35

#define CORRECTION_ANGLE 35

#define FOLLOW_CUBE_DEAD_TIME 250

// ================ UART Communication ================
#define RX_PIN D0
#define TX_PIN D1
SoftwareSerial cameraSerial(RX_PIN, TX_PIN);
String receivedMessage = "";
String command = "";
String current_color = "";

// ================ Turns count and direction ================
int turn_direction = 0;
int turn_count = 0;
const int max_turns = 12;
unsigned long lastTurnTime = 0, lastLineDetectedTime = 0;

long last_follow_cube = 0;


// ================ Avoid Cubes Variables ================
float follow_cube_angle = 0;  // PID steering correction for cube following.

unsigned long last_cube_time = 0;  // remember when we last avoided one


// ================ Robot States ================
enum RobotState {
  PID,
  FOLLOW_CUBE,
  AVOID_CUBE,
  AFTER_CUBE,
  PARK
};

RobotState currentState = PID;
char cube_avoid_direction = 'R';  // 'R' for red cube avoidance, 'L' for green cube avoidance
float desiredSteering = 0.0;
 
// ================ Debug Mode ================
bool debug = false;
bool debuggyro = false;
bool debugcam = false;
bool firstcube = false;


void setup() {

  //debug_distance_infinite(LEFT_DIR);

  steering_servo_setup();
  motor_driver_setup();
  impeller_setup();

  pinMode(LED_BUILTIN, OUTPUT);
  pinMode(DEBUG_LED1, OUTPUT);
  pinMode(DEBUG_LED2, OUTPUT);

  pinMode(PWM_DIST_LEFT, INPUT);
  pinMode(PWM_DIST_RIGHT, INPUT);
  pinMode(PWM_DIST_FRONT, INPUT);
  pinMode(PWM_DIST_BACK, INPUT);


  encoder_setup();

  Serial.begin(115200);

  cameraSerial.begin(19200);
  while (!cameraSerial)
    ;
  blink_led(DEBUG_LED1, 200);

  gyro_setup();
  blink_led(DEBUG_LED2, 200);

  digitalWrite(DEBUG_LED2, HIGH);
  pinMode(START_BTN, INPUT_PULLUP);

  while (digitalRead(START_BTN) == 1) {
    move(0);
    flush_messages();
  }

  //move_gyro_until_side_detect_cycle(LEFT_DIR, park_speed, current_angle_gyro);

  setImpeller(impeller_speed);
  delay(500);

  digitalWrite(DEBUG_LED1, HIGH);
  custom_delay(500);

  // Start from parking
  if (RUN_MODE == 1) {
    if (readDistanceMM(LEFT_DIR) > readDistanceMM(RIGHT_DIR)) {  // exit right/.
      move_until_angle_max(exit_speed, 75);

      move(65);
      delay(100);

      turn_direction = 1;
      move_until_angle_max(exit_speed, 0);

      move_straight_on_gyro(-robot_speed, 1400);
    } else {  // exit left
      move_until_angle_max(exit_speed, -70);

      move(65);
      delay(100);

      turn_direction = -1;

      move_until_angle_max(exit_speed, 0);

      move_straight_on_gyro(-robot_speed, 1800);
    }
  }
}

void loop() {

  // 1) Max‐turns timeout
  if (turn_count >= max_turns || current_angle_gyro == 1080) {
    if (RUN_MODE == 1) {
      currentState = PARK;
    } else {
      unsigned long t0 = millis();
      while (millis() - t0 < 1400) {
        read_gyro_data();
        double error = current_angle_gyro - gz;
        pid_error = error * kp + (pid_error - pid_last_error) * kd;
        pid_last_error = pid_error;
        steer(pid_error);
        move(robot_speed);
      }
      stop_motor();
      if (debug) Serial.println("Maximum turns reached. Stopping...");
      while (true)
        ;
    }
  }

  // 2) Fresh gyro read and flush camera
  read_gyro_data();

  // 3) State‐machine drive logic
  switch (currentState) {

    case PID:
      {
        // PID straight‐drive
        double err = current_angle_gyro - gz;
        pid_error = (err)*kp + (pid_error - pid_last_error) * kd;
        pid_last_error = pid_error;
        steer(pid_error);
        move(robot_speed);
        break;
      }

    case FOLLOW_CUBE:
      {
        if (millis() - last_follow_cube > FOLLOW_CUBE_DEAD_TIME) {
          currentState = PID;
        }
        // steer toward cube
        steer(follow_cube_angle);
        move(robot_speed);
        break;
      }

    case AVOID_CUBE:
      {
        // avoidance maneuver
        pass_cube(cube_avoid_direction);
        break;
      }

    case AFTER_CUBE:
      {
        int angle_addition = (cube_last == 1) ? 0 : 0;
        double err = current_angle_gyro - gz + cube_last * (CORRECTION_ANGLE + angle_addition);
        if (abs(err) < 5) {
          if (-cube_last == turn_direction) {
            move_cm(5, robot_speed, current_angle_gyro + -1 * cube_last * (CORRECTION_ANGLE + angle_addition));
          } else {
            move_cm(5, robot_speed, current_angle_gyro + -1 * cube_last * (CORRECTION_ANGLE + angle_addition));
          }
          currentState = PID;
        } else {
          pid_error = (err)*kp + (pid_error - pid_last_error) * kd;
          pid_last_error = pid_error;
          steer(pid_error);
        }
        move(robot_speed);
        //flush_messages();
        break;
      }

    case PARK:
      {
        // in functions.ino
        break;
      }
  }

  // 4) Read & dispatch any new OpenMV commands
  while (cameraSerial.available() > 0) {
    char c = cameraSerial.read();
    if (c == '\n') {
      // Normalize & execute
      receivedMessage.trim();
      receivedMessage.toUpperCase();
      execute_command(receivedMessage);
      receivedMessage = "";
      flush_messages();
    } else {
      receivedMessage += c;
    }
  }

  //Serial.println(currentState);
}

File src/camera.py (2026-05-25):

import sensor
import time
from machine import UART, LED

# -------- DEBUG FLAG --------
DEBUG = False

# -------- Camera & Sensor Setup --------
sensor.reset()
sensor.set_pixformat(sensor.RGB565)
sensor.set_framesize(sensor.QVGA)       # QVGA: 320x240

sensor.set_vflip(True)
sensor.set_hmirror(True)

# Disable auto settings for stable color tracking.
# RT1062 uses the OV5640 sensor, so you may need to retune thresholds/exposure.
sensor.set_auto_gain(False)
sensor.set_auto_whitebal(False)
sensor.set_auto_exposure(False, exposure_us=16000)

sensor.skip_frames(time=2000)
clock = time.clock()

# -------- UART & LED Setup --------
# RT1062 UART is on P4/P5:
# P4 = UART1 TX  -> connect to robot RX
# P5 = UART1 RX  -> connect to robot TX, optional if you only send data
# GND must be common.
# IMPORTANT: RT1062 I/O is 3.3 V only, not 5 V tolerant.
uart = UART(1, 19200, timeout_char=200)

red_led = LED("LED_RED")
green_led = LED("LED_GREEN")
blue_led = LED("LED_BLUE")


def leds_off():
    red_led.off()
    green_led.off()
    blue_led.off()


# Blink yellow (green + red) to indicate ready/qualification mode
green_led.on()
red_led.on()
time.sleep_ms(500)
leds_off()
time.sleep_ms(500)

# -------- Color Thresholds (LAB Space) --------
# These are copied from your H7 Plus code.
# Because RT1062 uses OV5640 instead of the H7 Plus sensor, retune in OpenMV IDE if needed.
red_threshold = [(35, 45, 28, 66, 11, 40), (29, 54, 21, 64, 6, 44)]
green_threshold = [(9, 24, -23, -12, -9, 21), (15, 42, -37, -11, -2, 30), (20, 41, -37, -11, -2, 30)]
blue_threshold = [(9, 76, -45, 27, -57, -8)]
orange_threshold = [(62, 91, -3, 43, 5, 69)]
pink_threshold = [(30, 70, 10, 60, -15, 15)]
black_threshold = [(0, 37, -26, 7, -17, 11)]

# -------- Define Regions of Interest (ROI) --------
img_h = sensor.height()
img_w = sensor.width()

cubes_roi = (0, int(img_h * 0.4), img_w, int(img_h * 0.6))
lines_roi = (5, int(img_h * 0.5), img_w - 10, int(img_h * 0.4))
wall_roi = (50, int(img_h * 0.5 - 18), img_w - 100, int(img_h * 0.2 - 10))
final_wall_roi = (30, 80, img_w - 60, img_h - 60)

# -------- Blob Filtering Parameters --------
min_cube_size = 500
min_line_size = 800
min_area = 10
min_valid_cube_area = 450
pink_wall_min_area = 5000
black_wall_min_area = 70000    # 7000
final_black_wall_min_area = 9000
min_black_height = 39

# -------- PD Parameters for Cube Following --------
kp_cube = 0.4
kd_cube = 2.4
pid_last_error = 0.0
follow_threshold = 5000

direction = 0  # 0 = not set, 1 = left, 2 = right


# -------- Helper Functions --------
def get_largest_blob(blobs):
    if not blobs:
        return None
    return max(blobs, key=lambda b: b.area())


def is_invalid_orange(orange_blob, red_blobs):
    # Ignore tall thin orange, or overlap logic with red blobs.
    if orange_blob.h() > orange_blob.w():
        return "ignore_orange"

    for r in red_blobs:
        overlap = (
            r.x() < orange_blob.x() + orange_blob.w() and
            r.x() + r.w() > orange_blob.x() and
            r.y() < orange_blob.y() + orange_blob.h() and
            r.y() + r.h() > orange_blob.y()
        )

        if overlap:
            red_area = r.area()
            orange_area = orange_blob.area()

            if red_area >= orange_area * 1.5:
                return "ignore_orange"
            elif orange_area >= red_area * 0.1:
                return "ignore_red"

    return None


def send(msg):
    uart.write(msg)


# -------- Main Loop --------
while True:
    clock.tick()
    img = sensor.snapshot()

    target_x = img_w // 2

    # ---- Detect Blobs ----
    red_blobs = img.find_blobs(
        red_threshold,
        roi=cubes_roi,
        pixels_threshold=min_cube_size,
        area_threshold=min_cube_size,
        merge=True
    )

    green_blobs = img.find_blobs(
        green_threshold,
        roi=cubes_roi,
        pixels_threshold=min_cube_size,
        area_threshold=min_cube_size,
        merge=True
    )

    blue_blobs = img.find_blobs(
        blue_threshold,
        roi=lines_roi,
        pixels_threshold=min_line_size,
        area_threshold=min_line_size,
        merge=True
    )

    orange_blobs = img.find_blobs(
        orange_threshold,
        roi=lines_roi,
        pixels_threshold=min_line_size,
        area_threshold=min_line_size,
        merge=True
    )

    # Main black wall detection.
    # Your old code overwrote black_blobs with final_wall_roi, so this keeps that final behavior.
    black_blobs = img.find_blobs(
        black_threshold,
        roi=final_wall_roi,
        pixels_threshold=final_black_wall_min_area,
        area_threshold=final_black_wall_min_area,
        merge=True
    )

    # ---- Get Largest Blobs ----
    red_cube = get_largest_blob([b for b in red_blobs if b.area() >= min_valid_cube_area])
    green_cube = get_largest_blob([b for b in green_blobs if b.area() >= min_valid_cube_area])
    blue_line = get_largest_blob([b for b in blue_blobs if b.area() >= min_area])
    orange_line = get_largest_blob([b for b in orange_blobs if b.area() >= min_area])
    black_blob = get_largest_blob(black_blobs)

    # ---- Detect Black Wall for Turns ----
    if black_blob:
        blob_h = black_blob.h()
        blob_area = black_blob.area()

        if blob_h >= min_black_height and blob_area >= black_wall_min_area:
            img.draw_rectangle(black_blob.rect(), color=(200, 200, 10))
            img.draw_string(
                black_blob.x(),
                black_blob.y() + blob_h - 10,
                "TURN",
                color=(255, 255, 255)
            )

            if DEBUG:
                print("Black wall: h={} area={}".format(blob_h, blob_area))

            #  send("BLACK\n")

    # ---- Choose Closest Cube ----
    candidates = []
    if red_cube:
        candidates.append(("R", red_cube))
    if green_cube:
        candidates.append(("G", green_cube))

    if candidates:
        color_char, cube = max(candidates, key=lambda x: x[1].area())
        area = cube.area()
        draw_color = (255, 0, 0) if color_char == "R" else (0, 255, 0)

        img.draw_rectangle(cube.rect(), color=draw_color)
        img.draw_cross(cube.cx(), cube.cy(), color=draw_color)
        img.draw_string(cube.x(), cube.y() + cube.h() - 10, str(area), color=draw_color)

        # PD on normalized error.
        error = (cube.cx() - target_x) / float(target_x)
        pid_output = kp_cube * error + kd_cube * (error - pid_last_error)
        pid_last_error = error

        if area < follow_threshold:
            send("S{:+.3f}\n".format(pid_output))

            if DEBUG:
                print("{} FOLLOW err:{:+.3f}, pid:{:+.3f}, area:{}".format(
                    "RED" if color_char == "R" else "GREEN",
                    error,
                    pid_output,
                    area
                ))
        else:
            send("RED\n" if color_char == "R" else "GREEN\n")
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

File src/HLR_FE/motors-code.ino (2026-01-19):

// -----------------------------------------------------------
//                     Motor Functions
// -----------------------------------------------------------
void motor_driver_setup() {
  pinMode(PWMA, OUTPUT);
  pinMode(DIRA, OUTPUT);
  ledcSetup(PWM_MOTOR_CHANNEL, PWM_MOTOR_FREQ, PWM_MOTOR_RESOLUTION);
  ledcAttachPin(PWMA, PWM_MOTOR_CHANNEL);
  move(0);
}

void move(int speed) {
  ledcWrite(PWM_MOTOR_CHANNEL, abs(speed));
  digitalWrite(DIRA, speed > 0 ? LOW : HIGH);
}

void impeller_setup() {
  pinMode(PWM_IMPELLER, OUTPUT);
  ledcSetup(PWM_IMPELLER_CHANNEL, PWM_IMPELLER_FREQ, PWM_IMPELLER_RESOLUTION);
  ledcAttachPin(PWM_IMPELLER, PWM_IMPELLER_CHANNEL);
}

void setImpeller(int _pwm) {
  ledcWrite(PWM_IMPELLER_CHANNEL, constrain(_pwm, 0, 255));
}

void stop_motor() {
  move(-3);
  delay(100);
  move(0);
}

// -----------------------------------------------------------------
// Helper: turn in place until you hit exactly target_angle
// -----------------------------------------------------------------
void move_until_angle(int speed, double target_angle) {
  int dir = (speed < 0) ? -1 : 1;

  read_gyro_data();
  double error = target_angle - gz;
  while (abs(error) >= 10) {
    read_gyro_data();
    error = target_angle - gz;
    pid_error = (error)*kp + (pid_error - pid_last_error) * kd;
    pid_last_error = pid_error;
    steer(pid_error * dir);
    move(robot_speed);
    flush_messages();
  }
}

void move_until_angle_max(int speed, double target_angle) {
    int dir = (speed < 0) ? -1 : 1;

    read_gyro_data();
    double error = target_angle - gz;
    move(speed);
    while (fabs(error) >= 10.0) {
        read_gyro_data();
        error = target_angle - gz;
        int steer_cmd;
        if (error * dir > 0) {
            steer_cmd =  1;
        } else {
            steer_cmd = -1;
        }
        steer(steer_cmd);
        move(speed);
        flush_messages();
    }
}


// -----------------------------------------------------------------
// Helper: drive forward target_cm while holding a given gyro angle
// -----------------------------------------------------------------
void move_cm_gyro(int target_cm, int speed, double hold_angle) {
  int dir = (speed < 0) ? -1 : 1;

  encoder_ticks = 0;
  move(speed);
  while (read_cm() < target_cm) {
    read_gyro_data();
    // PID to hold hold_angle
    double err = hold_angle - gz;
    pid_error = err * kp + (pid_error - pid_last_error) * kd;
    pid_last_error = err;
    steer(pid_error * dir);
    flush_messages();
  }
}

// -----------------------------------------------------------
//           ISR & setup for single-edge counting
// -----------------------------------------------------------
void IRAM_ATTR encoderISR() {
  // On A’s rising edge, read B. If B==HIGH we’re turning “forward”
  if (digitalRead(ENCODER_B)) {
    encoder_ticks++;
  } else {
    encoder_ticks--;
  }
}

void encoder_setup() {
  // Enable pull-ups so A/B never float
  pinMode(ENCODER_A, INPUT_PULLUP);
  pinMode(ENCODER_B, INPUT_PULLUP);
  // Attach only A’s rising edge:
  attachInterrupt(digitalPinToInterrupt(ENCODER_A), encoderISR, RISING);
  encoder_ticks = 0;
}

float read_cm() {
  noInterrupts();
  int32_t t = encoder_ticks;
  interrupts();

  float dist_mm = t * MM_PER_TICK;
  float dist_cm = dist_mm / 10.0f;
  //Serial.printf("ticks=%ld  dist_cm=%.2f\n", t, dist_cm);
  return dist_cm;
}

void move_cm(int target_cm, int speed, double gyro_offset) {
  noInterrupts();
  encoder_ticks = 0;
  interrupts();

  pid_last_error = 0;
  pid_error = 0;

  move(speed);
  while (read_cm() < target_cm) {
    read_gyro_data();
    double error = gyro_offset - gz;
    pid_error = error * kp + ((error - pid_last_error) * kd);
    pid_last_error = error;

    double sign = (speed < 0) ? -1.0 : 1.0;
    steer(pid_error * sign);

    move(speed);
    flush_messages();
  }
}


// -----------------------------------------------------------
//                    Steering Functions
// -----------------------------------------------------------
void steering_servo_setup() {
  steeringServo.attach(STEERING_SERVO);
  delay(100);

  steeringServo.write(STEERING_LEFT);
  delay(300);
  steeringServo.write(STEERING_RIGHT);
  delay(300);
  steeringServo.write(STEERING_CENTER);
  delay(300);
}

void steer(double steering_angle) {
  // Clamp input between -1 and 1
  if (steering_angle > 1)  steering_angle = 1;
  if (steering_angle < -1) steering_angle = -1;

  // Map to servo range
  steering_angle = map_double(steering_angle, -1, 1, STEERING_LEFT, STEERING_RIGHT);
  steeringServo.write(steering_angle);
}

void move_straight_on_gyro(double speed, long duration_ms) {
  int sign = speed >= 0 ? 1 : -1;

  unsigned long start_time = millis();
  while (millis() - start_time < duration_ms) {
    read_gyro_data();
    double err = current_angle_gyro - gz;  // try to hold a constant angle
    pid_error = (err)*kp + (pid_error - pid_last_error) * kd;
    pid_last_error = pid_error;

    steer(pid_error * sign);
    move(speed);
    cameraSerial.flush();
    flush_messages();
  }
}
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

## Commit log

2026-05-25 Rename impeller-fan (1).stl to impeller-fan.stl
    [impeller-fan.stl]
2026-05-31 Update print statement from 'Hello' to 'Goodbye'
2026-11-07 Create 03-power-sensors
2026-11-08 Enhance documentation on motor driver and steering system
    Added detailed information about the IFX9201SG motor driver, including specifications and reasons for selection. Expanded on the steering system design and its advantages for the robot's maneuverabil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
2026-11-10 Revise reproducibility documentation and version recording
    Updated documentation on reproducibility and version recording for Arduino IDE and OpenMV IDE. Added steps for capturing build environment and firmware information.
2026-11-10 Clarify CAD model and motor variant details
    Updated language for clarity regarding CAD model dimensions and motor specifications.
2026-11-11 Revise calibration details and illustrative examples`
    Updated illustrative values and descriptions for calibration and measurement sections. Clarified the use of physical readings and added context to the recording table.
